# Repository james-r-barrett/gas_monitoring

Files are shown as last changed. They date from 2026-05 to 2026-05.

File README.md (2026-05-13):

# Canary Gas Monitoring

An open-source, networked gas monitoring system for laboratory growth chambers, built around the ESP32-S3 microcontroller. Measures CO₂ (and optionally O₂) continuously, logs data to an onboard SD card, and pushes readings to a central Grafana dashboard via a Raspberry Pi hub.

---

## Features

- **Two sensor variants** — CO₂-only and combined CO₂/O₂
- **Local web interface** — connect directly to each sensor's WiFi hotspot to view live readings, graphs, calibration logs, and download CSV data
- **Networked monitoring** — sensors push to a Raspberry Pi hub, which forwards to Grafana Cloud for remote access
- **Offline capable** — all data logged to SD card indefinitely; Pi connection is optional
- **Automatic time sync** — from Raspberry Pi on connection, or from any browser as fallback
- **Configurable** — read interval, graph window, device name, location, WiFi credentials all adjustable from the web interface without reflashing
- **Calibration** — K30 CO₂ sensor calibration (0 ppm and 400 ppm) via web interface and touchscreen; O₂ sensor via hardware button
- **Optional solenoid control** — for automated CO₂ dosing (hardware provision included)

---

## Repository Structure

```
gas-monitor/
├── hardware/
│   ├── bom/                    # Bills of materials (CSV)
│   └── schematics/             # Wiring schematics (SVG/PDF)
├── firmware/
│   ├── co2_monitor/            # CO₂-only firmware (Arduino sketch)
│   └── co2_o2_monitor/         # CO₂ + O₂ firmware (Arduino sketch)
├── server/                     # Raspberry Pi server (Python/Flask)
├── laptop-bridge/              # USB sensor bridge scripts (Windows/Linux)
└── docs/
    └── assembly/               # Step-by-step build guide with images
```

---

## Sensor Variants

| Feature | CO₂ only | CO₂ + O₂ |
|---|---|---|
| CO₂ measurement | ✓ K30 NDIR (0–10,000 ppm) | ✓ K30 NDIR (0–10,000 ppm) |
| O₂ measurement | — | ✓ SEN0322 (0–25%) |
| Display | ✓ 1.47" touchscreen | ✓ 1.47" touchscreen |
| SD logging | ✓ | ✓ |
| Local web UI | ✓ | ✓ |
| Pi push | ✓ | ✓ |
| O₂ sensor lifetime | — | ~2 years (replaceable) |

---

## Quick Start

1. See [`hardware/bom/`](hardware/bom/) for the parts list
2. See [`docs/assembly/`](docs/assembly/) for the build guide
3. See [`firmware/`](firmware/) for Arduino IDE setup and flashing instructions
4. See [`server/`](server/) for Raspberry Pi setup
5. See [`laptop-bridge/`](laptop-bridge/) for the USB analyser bridge (optional)

---

## System Overview

```
┌─────────────────────┐     WiFi (GasMonitor AP)    ┌──────────────────────┐
│  ESP32 sensor unit  │ ──────────────────────────► │   Raspberry Pi hub   │
│  (one per chamber)  │                             │                      │
└─────────────────────┘                             │  InfluxDB  (local)   │
                                                    │  Flask receiver      │
┌─────────────────────┐     USB serial + WiFi       │  → Grafana Cloud     │
│  Windows/Linux      │ ──────────────────────────► │                      │
│  laptop (optional)  │                             └──────────────────────┘
│  Minir-5 + K30 1%   │
└─────────────────────┘
```

---

## Licence

see [LICENSE](LICENSE)

## Citation

If you use this system in published research, please cite this repository:

> Barrett, J.R. (2026). Lab Gas Monitor. GitHub. https://github.com/james-r-barrett/gas-monitor

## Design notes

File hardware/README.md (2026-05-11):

# Hardware

This folder contains all hardware documentation for the gas monitor sensor units.

```
hardware/
├── bom/            # Bills of materials (CSV) — one per sensor variant
├── schematics/     # Wiring schematics
└── 3d-print/       # 3D print files and print settings
```

## Sensor Variants

There are two hardware variants. They share the same ESP32-S3 base platform and differ only in the addition of the O₂ sensor and a modified enclosure lid.

### CO₂-only

The standard variant. Measures CO₂ concentration using the SenseAir K30 NDIR sensor. Suitable for the majority of growth chamber applications.

### CO₂ + O₂

Adds a DFRobot SEN0322 electrochemical oxygen sensor to the I²C bus. The O₂ sensor shares the same I²C bus as the touchscreen controller (both run at 3.3V logic but the SEN0322 requires a 5V VCC supply). The enclosure lid has an additional port for the O₂ sensor body.

## Key Design Decisions

**Level shifter for K30:** The SenseAir K30 operates at 5V UART logic. The ESP32-S3 GPIO is 3.3V. A Pololu 4-channel bidirectional level shifter is used between them. The LV reference must be connected to the ESP32's 3.3V rail and the HV reference to the USB 5V (VBUS) rail.

**O₂ sensor power:** The SEN0322 operates at 3.3-5.5V VCC with  3.3V-compatible I²C logic. It may be powered from VBUS (5V), or the 3.3V regulator. The I²C SDA/SCL lines connect directly to the ESP32 GPIO without a level shifter.

**SD card interface:** The ESP32-S3 uses 4-bit SDMMC mode for SD card access, which is significantly faster than SPI mode. The pin assignments are fixed by the SDMMC peripheral and cannot be remapped.

**Power budget:** At peak load the system draws approximately 500–600 mA:
- K30 CO₂ sensor: ~200 mA
- ESP32-S3 + display: ~300 mA  
- SEN0322 O₂ sensor: <10 mA
- Other: <20 mA

A quality USB-C supply rated at ≥2A is recommended. Cheap supplies cause intermittent brown-outs that can corrupt SD card writes.

## I²C Bus

The I²C bus (SDA GPIO42, SCL GPIO41) is shared between:

- AXS5106L touch controller (address 0x63)
- SEN0322 O₂ sensor (address 0x73, set by dial switch position 3) — CO₂+O₂ variant only

There are no address conflicts between these devices.

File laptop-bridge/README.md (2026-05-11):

# Laptop Bridge

Python scripts for reading USB-connected gas analysers on a Windows or Linux laptop and pushing their data to the Raspberry Pi hub. This is an optional component — only needed if you have analysers connected via USB rather than the ESP32-based sensor units.

In our lab the laptop monitors two mixing bottle supplies:

- **Minir-5** (orange bottle) — 1–5% CO₂ mix, COM3 / `/dev/ttyMINIR`
- **K30 1%** (clear bottle) — ambient/low CO₂ supply, COM4 / `/dev/ttyK30`

---

## Files

| File | Purpose |
|---|---|
| `minir_pusher.py` | Reads Minir-5 via ASCII protocol and pushes to Pi |
| `k30_pusher.py` | Reads K30 via Modbus binary protocol and pushes to Pi |
| `minir_calibration.py` | GUI calibration tool for the Minir-5 |
| `k30_calibration.py` | GUI calibration tool for the K30 |

---

## Requirements

```bash
pip install pyserial requests
```

On Linux, also add your user to the `dialout` group and log out/in:
```bash
sudo usermod -a -G dialout $USER
```

---

## Configuration

Edit the top of each pusher script to match your setup:

```python
# minir_pusher.py
SERIAL_PORT   = "COM3"          # Windows
# SERIAL_PORT = "/dev/ttyMINIR" # Linux (with udev rule)
PI_HOST       = "192.168.50.1"
PI_PORT       = 5000
SENSOR_ID     = "1-5% Mix"
LOCATION      = "Orange mixing bottle"

# k30_pusher.py
SERIAL_PORT   = "COM4"          # Windows
# SERIAL_PORT = "/dev/ttyK30"   # Linux (with udev rule)
PI_HOST       = "192.168.50.1"
PI_PORT       = 5000
SENSOR_ID     = "<400 ppm Mix"
LOCATION      = "Clear mixing bottle"
```

---

## Running

### Windows — run both scripts together

Create `start_sensors.bat`:
```batch
@echo off
cd /d C:\path\to\laptop-bridge
start "Minir5" python minir_pusher.py
start "K30"   python k30_pusher.py
```

Drop a shortcut to this file in `shell:startup` to run on login.

### Linux — run as systemd services

Create `/etc/systemd/system/minir-pusher.service`:
```ini
[Unit]
Description=Minir-5 Gas Sensor Pusher
After=network.target

[Service]
ExecStart=/usr/bin/python3 /home/user/laptop-bridge/minir_pusher.py
Restart=always
RestartSec=10
User=user

[Install]
WantedBy=multi-user.target
```

Repeat for `k30-pusher.service`. Then:
```bash
sudo systemctl enable --now minir-pusher k30-pusher
```

---

## Linux: Persistent Serial Port Names (recommended)

On Linux the USB serial ports can be assigned different device names (`/dev/ttyUSB0`, `/dev/ttyUSB1`) depending on plug order. Use udev rules to assign stable names.

Find the USB serial numbers:
```bash
udevadm info -a -n /dev/ttyUSB0 | grep -E "serial|idVendor|idProduct"
udevadm info -a -n /dev/ttyUSB1 | grep -E "serial|idVendor|idProduct"
```

Create `/etc/udev/rules.d/99-gas-sensors.rules`:
```
SUBSYSTEM=="tty", ATTRS{idVendor}=="XXXX", ATTRS{serial}=="MINIR_SERIAL_HERE", SYMLINK+="ttyMINIR"
SUBSYSTEM=="tty", ATTRS{idVendor}=="XXXX", ATTRS{serial}=="K30_SERIAL_HERE",   SYMLINK+="ttyK30"
```

Reload:
```bash
sudo udevadm control --reload-rules && sudo udevadm trigger
```

The devices will now always appear as `/dev/ttyMINIR` and `/dev/ttyK30`.

---

## Protocols

### Minir-5 (ASCII)

| Command | Sends | Response | Description |
|---|---|---|---|
| `Z\r\n` | — | `  Z XXXXX` | Read CO₂ — value × 10 = ppm |
| `U\r\n` | — | `  U XXXXX` | Unlock for calibration |
| `X NNNN\r\n` | — | `  X XXXXX` | Calibrate — NNNN = target_ppm / 10 |

Example: `Z 03050` → 30,500 ppm

### K30 (Modbus binary)

| Bytes | Description |
|---|---|
| `FE 44 00 08 02 9F 25` | Read CO₂ command (7 bytes) |
| `FE 44 02 HH LL XX XX` | Response — CO₂ = (HH × 256 + LL) ppm |

Example response `FE 44 02 00 61 79 0C` → bytes[3:5] = `0x00 0x61` = 97 ppm

---

## Calibration Tools

The calibration tools (`minir_calibration.py` and `k30_calibration.py`) are standalone GUI applications built with Python's tkinter — no additional packages required beyond pyserial.

**Important:** The pusher script and calibration tool cannot both have the serial port open simultaneously. Stop the relevant pusher before running the calibration tool, then restart it afterwards.

### K30 calibration tool

- Connects to K30 on the selected COM port
- Shows live CO₂ reading (updates every 5 seconds)
- Provides 0 ppm and 400 ppm calibration buttons with confirmation dialogs
- Calibration sequence: sends unlock command → calibration command → 8-second settle → reads back result
- Includes on-screen reminders about the departmental compressed air line limitation

### Minir-5 calibration tool

- Connects to Minir-5 on the selected COM port
- Shows live CO₂ reading (updates every 5 seconds)
- Accepts any target concentration (free entry + presets at 1k, 5k, 10k, 20k, 30k, 50k ppm)
- Calibration sequence: `U` unlock → `X NNNN` calibration command → settle → verify confirmed value
- Warns if the sensor's confirmed calibration point differs from the target by more than 100 ppm

---

## Troubleshooting

| Problem | Action |
|---|---|
| `Cannot open COM3/COM4` | Check Device Manager — port may have changed number. Update `SERIAL_PORT` in script. |
| No data in Grafana | Confirm laptop is connected to `GasMonitor` WiFi. Check script log output for POST errors. |
| Readings are ×10 wrong | Verify Minir-5 multiplier — raw value × 10 = ppm for the Minir protocol. |
| K30 returns -1 or no response | Check USB cable and level shifter wiring. Try power-cycling the K30. |
| Calibration tool won't connect | Stop the pusher script first — both tools cannot share the serial port. |

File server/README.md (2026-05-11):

# Raspberry Pi Server

The Raspberry Pi acts as the central hub for the sensor network. It:

1. Broadcasts a WiFi access point (`GasMonitor`) that the sensors connect to
2. Provides time synchronisation to sensors on connection
3. Receives sensor readings via HTTP POST
4. Stores readings in a local InfluxDB instance
5. Forwards readings to Grafana Cloud

---

## Hardware

- Raspberry Pi 5 (2GB RAM tested; 4GB recommended for comfort)
- microSD card for Pi OS (16GB minimum)
- Ethernet cable (for network connection)
- Power supply (official Pi 5 USB-C 27W recommended)

---

## OS Setup

Flash **Raspberry Pi OS Lite (64-bit)** using [Raspberry Pi Imager](https://www.raspberrypi.com/software/).

In the Imager settings before flashing:

- Hostname: `gasmonitor.local`
- Enable SSH
- Set username and password

Boot the Pi and SSH in:
```bash
ssh pi@gasmonitor.local
```

Update:
```bash
sudo apt update && sudo apt upgrade -y
```

---

## WiFi Access Point Setup

The Pi broadcasts `GasMonitor` on its wireless interface while using ethernet for university network connectivity.

> ⚠️ **For most university networks it is not permitted to operate the Pi as an access point to the university. IPv4 forwarding must be disabled.**

### Disable IPv4 forwarding
Disable immediately:
```bash
sudo sysctl -w net.ipv4.ip_forward=0
```
Make persistent:
```bash
sudo nano /etc/sysctl.conf
```
Add:
```
net.ipv4.ip_forward=0
```
Apply:
```
sudo sysctl -p
```

### Install packages
```bash
sudo apt install -y hostapd dnsmasq
sudo systemctl stop hostapd dnsmasq
```

### Static IP for wlan0
```bash
sudo nano /etc/dhcpcd.conf
```
Add at the bottom:
```
interface wlan0
    static ip_address=192.168.50.1/24
    nohook wpa_supplicant
```

### DHCP server (dnsmasq)
```bash
sudo mv /etc/dnsmasq.conf /etc/dnsmasq.conf.orig
sudo nano /etc/dnsmasq.conf
```
```
interface=wlan0
dhcp-range=192.168.50.10,192.168.50.50,255.255.255.0,24h
domain=local
address=/gasmonitor.local/192.168.50.1
```

### Access point (hostapd)
```bash
sudo nano /etc/hostapd/hostapd.conf
```
```
interface=wlan0
driver=nl80211
ssid=GasMonitor
hw_mode=g
channel=7
wpa=2
wpa_passphrase=your set password here
wpa_key_mgmt=WPA-PSK
rsn_pairwise=CCMP
```

```bash
sudo nano /etc/default/hostapd
# Change: DAEMON_CONF="" → DAEMON_CONF="/etc/hostapd/hostapd.conf"
```

### Enable and reboot
```bash
sudo systemctl unmask hostapd
sudo systemctl enable hostapd dnsmasq
sudo reboot
```

After reboot, `GasMonitor` WiFi should be visible. Connect your laptop to it and verify SSH still works at `192.168.50.1`.

---

## InfluxDB

```bash
wget -q https://repos.influxdata.com/influxdata-archive_compat.key
echo '393e8779c89ac8d958f81f942f9ad7fb82a25e133faddaf92e15b16e6ac9ce4c influxdata-archive_compat.key' | sha256sum -c
cat influxdata-archive_compat.key | gpg --dearmor | sudo tee /etc/apt/trusted.gpg.d/influxdata-archive_compat.gpg > /dev/null
echo 'deb [signed-by=/etc/apt/trusted.gpg.d/influxdata-archive_compat.gpg] https://repos.influxdata.com/debian stable main' | sudo tee /etc/apt/sources.list.d/influxdata.list
sudo apt update && sudo apt install -y influxdb2
sudo systemctl enable --now influxdb
```

Open `http://192.168.50.1:8086` in a browser connected to `GasMonitor` WiFi and complete the setup wizard:

- Organisation: `lab`
- Bucket: `sensors`
- Generate an **All Access API token** and save it — you'll need it below

---

## Flask Receiver

### Install dependencies
```bash
sudo apt install -y python3-flask
pip3 install influxdb-client requests --break-system-packages
```

### Install server script
```bash
mkdir ~/gas_project
cp server.py ~/gas_project/
nano ~/gas_project/server.py
# Edit: paste your InfluxDB token into LOCAL_TOKEN
# Edit: paste your Grafana Cloud credentials into CLOUD_USER and CLOUD_TOKEN
```

### Test
```bash
python3 ~/gas_project/server.py
```

From another terminal or device on the `GasMonitor` network:
```bash
curl -X POST http://192.168.50.1:5000/sensor-data \
  -H "Content-Type: application/json" \
  -d '{"sensor_id":"test","location":"test","co2":500}'
```

You should see `{"status":"success"}`.

### Run as a system service
```bash
sudo nano /etc/systemd/system/gasreceiver.service
```
```ini
[Unit]
Description=Gas Sensor Data Receiver
After=network.target influxdb.service
Requires=influxdb.service

[Service]
ExecStart=/usr/bin/python3 /home/pi/gas_project/server.py
WorkingDirectory=/home/pi/gas_project
Restart=always
RestartSec=5
User=pi

[Install]
WantedBy=multi-user.target
```
```bash
sudo systemctl enable --now gasreceiver
sudo journalctl -u gasreceiver -f   # watch logs
```

---

## Grafana

```bash
sudo mkdir -p /etc/apt/keyrings/
wget -q -O - https://apt.grafana.com/gpg.key | gpg --dearmor | sudo tee /etc/apt/keyrings/grafana.gpg > /dev/null
echo "deb [signed-by=/etc/apt/keyrings/grafana.gpg] https://apt.grafana.com stable main" | sudo tee /etc/apt/sources.list.d/grafana.list
sudo apt update && sudo apt install -y grafana
sudo systemctl enable --now grafana-server
```

Access local Grafana at `http://192.168.50.1:3000` (default login: `admin` / `admin`).

Add InfluxDB as a data source:

- Type: **InfluxDB**
- Query language: **Flux**
- URL: `http://localhost:8086`
- Organisation: `lab`
- Token: paste your InfluxDB token
- Default bucket: `sensors`

---

## Grafana Cloud (optional)

For remote access without a VPN, the server script forwards readings to Grafana Cloud using the InfluxDB line protocol over HTTPS. Configure `CLOUD_URL`, `CLOUD_USER`, and `CLOUD_TOKEN` in `server.py` with credentials from your Grafana Cloud stack.

---

## API Endpoints

The receiver exposes the following HTTP endpoints:

| Endpoint | Method | Description |
|---|---|---|
| `/sensor-data` | POST | Receive a reading from a sensor |
| `/time` | GET | Return current Unix timestamp (used by sensors for time sync) |
| `/health` | GET | Health check |
| `/sensors` | GET | List last reading from each sensor |

### POST /sensor-data payload

```json
{
  "sensor_id": "chamber1",
  "location": "Growth Room A",
  "co2": 850,
  "o2": 20.91,
  "uptime": 3600,
  "timestamp": 1746540130
}
```

Fields `o2`, `uptime`, and `timestamp` are optional. If `timestamp` is provided and valid (>1700000000), it is used as the InfluxDB write time; otherwise the Pi's system time is used.

---

## Troubleshooting

| Problem | Action |
|---|---|
| `GasMonitor` WiFi not appearing | `sudo systemctl status hostapd` — check for errors |
| Sensors not connecting to Pi | Verify sensor WiFi credentials match `GasMonitor` / `your set password` |
| No data in InfluxDB | Check `sudo journalctl -u gasreceiver -f` for POST errors |
| Timestamps wrong in Grafana | Run `timedatectl` on Pi — NTP must be active and synced |
| Pi can't reach Grafana Cloud | Check ethernet connection: `curl https://grafana.net` |

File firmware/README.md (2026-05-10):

# Firmware

Two Arduino sketches are provided. Choose the one matching your hardware variant.

| Folder | Variant | Sketch file |
|---|---|---|
| `co2_monitor/` | CO₂ only | `co2_monitor.ino` |
| `co2_o2_monitor/` | CO₂ + O₂ | `co2_o2_monitor.ino` |

---

## Prerequisites

### Arduino IDE

Download and install [Arduino IDE 2.x](https://www.arduino.cc/en/software) (2.0 or later recommended).

### ESP32 Board Package

1. Open Arduino IDE → **File → Preferences**
2. In *Additional boards manager URLs*, add:
   ```
   https://raw.githubusercontent.com/espressif/arduino-esp32/gh-pages/package_esp32_index.json
   ```
3. Open **Tools → Board → Boards Manager**
4. Search for `esp32` and install **esp32 by Espressif Systems** (version 3.x recommended)

### Board Selection

- Board: **ESP32S3 Dev Module**
- PSRAM: **OPI PSRAM** (required — the firmware allocates history buffers in PSRAM)
- Flash size: **16MB**
- Partition scheme: **Default 4MB with spiffs** (or any scheme with ≥1.5MB app)
- Upload speed: **921600**

> **Important:** PSRAM must be enabled. Without it the large history buffers (up to 345,600 readings) will exhaust internal SRAM immediately.

---

## Required Libraries

Install all of the following via **Tools → Manage Libraries** in Arduino IDE:

| Library | Author | Install name |
|---|---|---|
| Arduino_GFX_Library | moononournation | `Arduino_GFX_Library` |
| esp_lcd_touch_axs5106l | — | Search `axs5106l` |
| DFRobot_OxygenSensor | DFRobot | `DFRobot_OxygenSensor` (CO₂+O₂ variant only) |

The following libraries are included with the ESP32 Arduino core and do not need separate installation:

- `WiFi`
- `WebServer`
- `Wire`
- `SD_MMC`
- `HTTPClient`

---

## Configuration

Before flashing, review the top of the sketch and adjust as needed:

```cpp
// WiFi access point credentials for this sensor's own hotspot
char apSSID[32] = "CO2Monitor";
char apPass[32] = "co2monitor123";

// Raspberry Pi network credentials (if using Pi hub)
const char* PI_SSID = "GasMonitor";
const char* PI_PASS = "*set your own*";
const char* PI_HOST = "192.168.50.1";
const int   PI_PORT = 5000;

// Sensor identity (also configurable via web UI without reflashing)
char deviceName[32] = "CO2 Monitor";
char sensorID[32]   = "sensor1";
char location[32]   = "chamber1";
```

All of these values can also be changed at runtime via the sensor's web interface at `192.168.4.1` — you do not need to reflash to rename a sensor or change WiFi credentials.

---

## Flashing

1. Connect the ESP32-S3 dev kit to your computer via USB-C
2. Open the sketch folder in Arduino IDE (`co2_monitor/co2_monitor.ino` or `co2_o2_monitor/co2_o2_monitor.ino`)
3. Select the correct port under **Tools → Port**
4. Click **Upload** (→)

If the board is not detected, hold the **BOOT** button on the ESP32 while pressing **Reset**, then release both and retry upload.

### First boot

On first boot with a blank SD card:
- The device will create `settings.json` on the SD card with default values
- Time sync will show a splash screen — connect to the sensor's WiFi hotspot and open `192.168.4.1` to sync time from your browser, or connect to the Raspberry Pi network to sync automatically

---

## SD Card Setup

Format the SD card as **FAT32** before first use. The firmware creates all required files automatically on first boot:

| File | Contents |
|---|---|
| `YYYY-MM.csv` | Monthly CO₂ (and O₂) log |
| `fallback.csv` | Readings taken before time sync (backdated on sync) |
| `settings.json` | Device configuration |
| `lasttime.txt` | Saved timestamp for reboot persistence |
| `lastcal.txt` | Most recent calibration record |
| `cal_log.csv` | Full calibration history |

---

## Operational Modes

The firmware operates in two modes automatically — no configuration required:

### Mode 1: Pi-connected (normal operation)
- Sensor connects to `GasMonitor` WiFi at boot
- Time is synced automatically from the Pi
- Readings are pushed to the Pi/Grafana every read cycle
- Green dot indicator shown on device display

### Mode 2: Standalone (Pi unavailable)
- Sensor shows a splash screen prompting time sync via browser
- Connect any device to the sensor's own WiFi hotspot
- Navigate to `192.168.4.1` — time syncs automatically from your browser
- Full local functionality continues (logging, web UI, graphs)
- Data recorded to `fallback.csv` until time sync; backdated automatically on sync

---

## Pin Reference

### Common to both variants

| Function | GPIO |
|---|---|
| Display SPI MOSI | 39 |
| Display SPI SCLK | 38 |
| Display CS | 21 |
| Display DC | 45 |
| Display RST | 40 |
| Display backlight | 46 |
| Touch SDA | 42 |
| Touch SCL | 41 |
| Touch RST | 47 |
| Touch INT | 48 |
| K30 TX (to sensor) | 43 |
| K30 RX (from sensor) | 44 |
| SD CLK | 16 |
| SD CMD | 15 |
| SD D0 | 17 |
| SD D1 | 18 |
| SD D2 | 13 |
| SD D3 | 14 |

### CO₂ + O₂ variant only

| Function | GPIO |
|---|---|
| O₂ sensor SDA | 42 (shared with touch) |
| O₂ sensor SCL | 41 (shared with touch) |
| O₂ sensor VCC | 3V3 |

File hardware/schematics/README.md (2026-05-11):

# Schematics

Wiring schematics for both sensor variants.

| File | Variant |
|---|---|
| `co2_schematic.png` | CO₂-only sensor |
| `co2_o2_schematic.png` | CO₂ + O₂ sensor |

---

## CO₂-only — Full Connection Reference

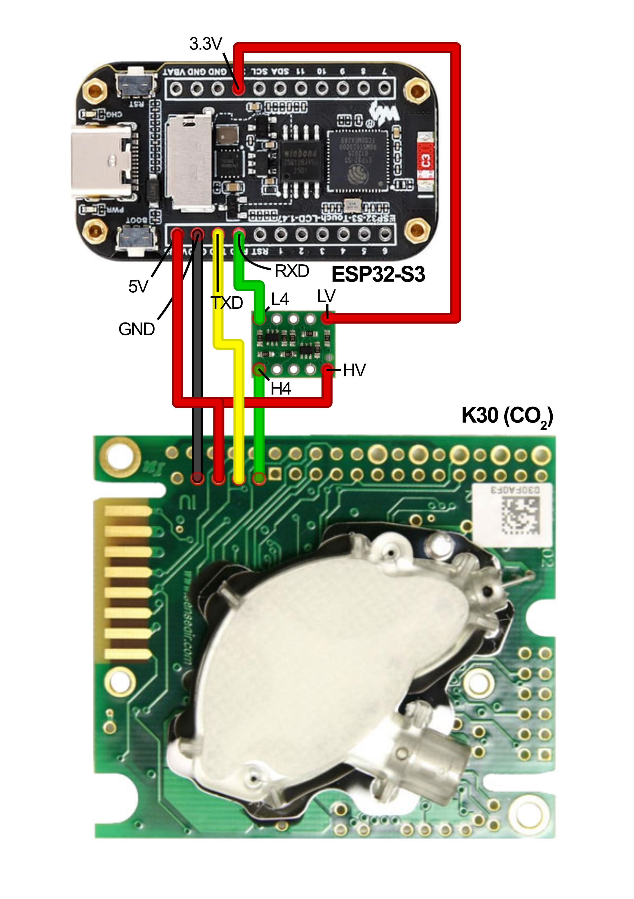
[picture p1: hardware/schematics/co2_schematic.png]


### Power

| From | To | Notes |
|---|---|---|
| USB-C 5V (VBUS) | ESP32 5V pin | Main supply |
| USB-C GND | ESP32 GND | Common ground |
| USB-C VBUS | Level shifter HV | 5V reference for K30 side |
| ESP32 3.3V | Level shifter LV | 3.3V reference for ESP32 side |

### Display (SPI — built into Waveshare dev kit)

| ESP32 GPIO | Function |
|---|---|
| 39 | SPI MOSI |
| 38 | SPI SCLK |
| 21 | Display CS |
| 45 | Display DC |
| 40 | Display RST |
| 46 | Backlight (PWM) |

> These connections are internal to the Waveshare board and require no external wiring.

### Touchscreen (I²C — built into Waveshare dev kit)

| ESP32 GPIO | AXS5106L pin | Notes |
|---|---|---|
| 42 | SDA | Internal to board |
| 41 | SCL | Internal to board |
| 47 | RST | Internal to board |
| 48 | INT | Internal to board |

> These connections are internal to the Waveshare board and require no external wiring.

### SD Card (SDMMC 4-bit — built into Waveshare dev kit)

| ESP32 GPIO | SD pin |
|---|---|
| 16 | CLK |
| 15 | CMD |
| 17 | D0 |
| 18 | D1 |
| 13 | D2 |
| 14 | D3 |

> These connections are internal to the Waveshare board and require no external wiring.

### K30 CO₂ Sensor (UART via level shifter)

| ESP32 GPIO | Level shifter | K30 pin | Notes |
|---|---|---|---|
| 43 (TX) | — | RXD | ESP32 TX → K30 RX |
| 44 (RX) | HV3 → LV3 | TXD | K30 TX → ESP32 RX |
| 3.3V | LV ref | — | Level shifter reference |
| VBUS (5V) | HV ref | — | Level shifter reference |
| GND | — | GND | Common ground |
| VBUS (5V) | — | G+ (VCC) | K30 power — must be 5V |

> **Note:** Do not use the K30's RST pin as the HV reference for the level shifter. Connect HV directly to the VBUS rail.

## CO₂ + O₂ — Additional Connections



All connections above apply, plus:

### SEN0322 O₂ Sensor (I²C, shared bus)

| SEN0322 pin | Connection | Notes |
|---|---|---|
| VCC | 3V3 (3.3V) | **3.3V not 5V** |
| GND | GND | Common ground |
| SDA | ESP32 GPIO42 | Shared with touch controller |
| SCL | ESP32 GPIO41 | Shared with touch controller |
| Dial switch | Position 3 | Sets I²C address to 0x73 |

---

## Schematic Notes

- All GND connections share a common ground rail.
- The Waveshare ESP32-S3 dev kit has an onboard 3.3V regulator. Do not exceed 600 mA total from VBUS.
- The level shifter RST pin (if present on your variant) is not used — leave it unconnected or tie to LV.
- GPIO pins 1–10 are all available for the solenoid or future expansion. GPIO1 is used in the firmware by default but any free GPIO can be substituted with a one-line firmware change.

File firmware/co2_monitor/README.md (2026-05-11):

# CO₂ Monitor Firmware

Arduino sketch for the **CO₂-only** sensor variant. For the combined CO₂ + O₂ variant see `../co2_o2_monitor/`.

## File

`co2_monitor.ino`

---

## What this firmware does

- Reads CO₂ concentration from a SenseAir K30 sensor over UART every 1–60 seconds (configurable)
- Displays live readings, trend indicator, and sparkline on the 1.47" touchscreen
- Logs all readings to a monthly CSV file on the SD card
- Hosts a local web interface at `192.168.4.1` (accessible from the sensor's own WiFi hotspot)
- Connects to the Raspberry Pi hub (`GasMonitor` WiFi) and pushes readings via HTTP POST
- Syncs time from the Pi on connection, or from a browser as fallback
- Stores min/max statistics over a rolling 12-hour window
- Supports K30 calibration (0 ppm and 400 ppm) from the web interface

---

## Setup

See the [firmware README](../README.md) for:
- Arduino IDE and board package installation
- Required libraries
- Board settings (PSRAM must be enabled)
- Flashing instructions

---

## Sensor-specific notes

### K30 UART wiring
The K30 runs at 5V UART logic and must be connected via a level shifter. See `hardware/schematics/` for the full wiring diagram.

### ABC (Automatic Baseline Correction)
The firmware disables ABC on every boot by sending the ABC-off command to the K30. This is essential for growth chamber use where the sensor is never exposed to outdoor air concentrations for the sustained periods ABC requires. Do not re-enable ABC.

### Calibration
Two calibration points are supported:
- **0 ppm** — using pure N₂ or a certified 0 ppm CO₂ / 21% O₂ / 79% N₂ mix
- **400 ppm** — using outdoor ambient air (preferred) or a certified reference gas

See the [calibration documentation](/docs/user-guide.md) for full procedure including the warning about using the departmental compressed air line.

---

## Display pages

Tap the main reading area to cycle through pages:

| Page | Content |
|---|---|
| Reading view | Live CO₂ value, trend arrow, 12h min/max, uptime/clock, sparkline |
| CO₂ graph | Full-resolution graph for the configured window (up to 96h) |

---

## Settings (configurable at runtime via web UI)

| Setting | Default | Description |
|---|---|---|
| Read interval | 5s | How often to poll the K30 |
| Graph window | 30 min | Time window for device display and web graph |
| Device name | CO2 Monitor | Shown on screen and used as Grafana sensor ID |
| Location | chamber1 | Location tag in Grafana |
| WiFi SSID | CO2Monitor | Sensor's own hotspot SSID |
| WiFi password | co2monitor123 | Sensor's own hotspot password |

All settings are saved to `settings.json` on the SD card and persist across reboots. WiFi changes require a reboot to take effect.

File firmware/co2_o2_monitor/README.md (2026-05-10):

# CO₂ + O₂ Monitor Firmware

Arduino sketch for the **combined CO₂ and O₂** sensor variant. For the CO₂-only variant see `../co2_monitor/`.

## File

`co2_o2_monitor.ino`

---

## What this firmware does

Everything the CO₂-only firmware does, plus:

- Reads O₂ concentration from a DFRobot SEN0322 sensor over I²C every read cycle
- Displays O₂ alongside CO₂ on the reading view with independent trend indicator
- Logs O₂ to the monthly CSV alongside CO₂ (`o2_pct` column)
- Includes O₂ in data pushed to the Raspberry Pi and Grafana
- Adds an O₂ graph as a third display page (cycle: reading → CO₂ graph → O₂ graph)
- Handles O₂ sensor absence gracefully — shows `--` if sensor not detected at boot

---

## Setup

See the [firmware README](../README.md) for:
- Arduino IDE and board package installation
- Required libraries — **DFRobot_OxygenSensor is additionally required for this variant**
- Board settings (PSRAM must be enabled)
- Flashing instructions

---

## Additional library

Install via Arduino IDE Library Manager:

| Library | Author |
|---|---|
| `DFRobot_OxygenSensor` | DFRobot |

---

## Sensor-specific notes

### SEN0322 I²C address
The O₂ sensor address is set by a dial switch on the board. **Set the dial to position 3** (I²C address `0x73`). This avoids conflict with the AXS5106L touch controller at `0x63`.

### SEN0322 power supply
The SEN0322 **must be powered from 5V (VBUS)**. Connecting VCC to the 3.3V rail will cause the electrochemical cell to give incorrect readings or fail to respond. The I²C SDA/SCL lines are 3.3V compatible and connect directly to the ESP32 GPIO.

### O₂ sensor initialisation
The firmware attempts to initialise the O₂ sensor with up to 5 retries at 500ms intervals during boot. If the sensor is not detected after all retries, the firmware continues without O₂ — all CO₂ functionality is unaffected. A retry loop is necessary because the SEN0322 requires ~2 seconds to stabilise after power-on.

### O₂ sensor lifetime
The electrochemical cell has a lifetime of approximately **2 years** from first use. Monitor for readings that drift consistently low or become unstable — this indicates the cell is near end of life. Replacement sensors are available from DFRobot.

### O₂ calibration
O₂ sensor calibration is performed by holding the **physical button on the back of the SEN0322 board** while the sensor is exposed to clean outdoor air (20.9% O₂). This is a hardware calibration and is not performed via the web interface. Under normal operating conditions recalibration should rarely be needed.

---

## Display pages

Tap the main reading area to cycle through three pages:

| Page | Content |
|---|---|
| Reading view | Live CO₂ and O₂ values, trend arrows, sparklines for both |
| CO₂ graph | Full-resolution CO₂ graph for the configured window |
| O₂ graph | Full-resolution O₂ graph for the configured window (auto-scaled) |

If the Pi is not connected and time has not been synced, tapping to the graph pages is blocked until time sync is complete.

---

## CSV log format

Monthly log files contain the following columns:

```
datetime,uptime_s,co2_ppm,o2_pct
2026-05-10 14:23:01,3601,842,20.91
```

---

## Settings (configurable at runtime via web UI)

| Setting | Default | Description |
|---|---|---|
| Read interval | 5s | How often to poll both sensors |
| Graph window | 30 min | Time window for device display and web graph |
| Device name | CO2 Monitor | Shown on screen and used as Grafana sensor ID |
| Location | chamber1 | Location tag in Grafana |
| WiFi SSID | CO2Monitor | Sensor's own hotspot SSID |
| WiFi password | co2monitor123 | Sensor's own hotspot password |

All settings are saved to `settings.json` on the SD card and persist across reboots.

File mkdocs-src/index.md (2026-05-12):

---
hide:
  - navigation
---

# Canary Gas Monitoring

<div class="hero-image">
  Assembled Lab Gas Monitor
</div>

<div class="hero-content">

An open-source, networked gas monitoring system for laboratory growth chambers, built around the ESP32-S3 microcontroller.

Continuously measures CO₂ (and optionally O₂), logs data locally to SD storage, and streams live telemetry to a central Grafana dashboard through a Raspberry Pi hub.

<div class="hero-tags">
  <span>ESP32-S3</span>
  <span>CO₂ Monitoring</span>
  <span>Grafana</span>
  <span>Open Source</span>
</div>

<div class="hero-buttons">
  <a href="https://github.com/james-r-barrett/gas_monitoring"
     target="_blank"
     class="hero-btn github-btn">

    <svg xmlns="http://www.w3.org/2000/svg"
         viewBox="0 0 496 512"
         width="16"
         height="16"
         fill="currentColor">

      <path d="M165.9 397.4c0 2-2.3 3.6-5.2 3.6-3.3.3-5.6-1.3-5.6-3.6 0-2 2.3-3.6 5.2-3.6 3-.3 5.6 1.3 5.6 3.6zM244.8 8C106.1 8 0 113.3 0 252c0 110.9 69.8 205.8 169.5 239.2 12.8 2.3 17.3-5.6 17.3-12.1 0-6.2-.3-40.4-.3-61.4 0 0-70 15-84.7-29.8 0 0-11.4-29.1-27.8-36.6 0 0-22.9-15.7 1.6-15.4 0 0 24.9 2 38.6 25.8 21.9 38.6 58.6 27.5 72.9 20.9 2.3-16 8.8-27.1 16-33.7-55.9-6.2-112.3-14.3-112.3-110.5 0-27.5 7.6-41.3 23.6-58.9-2.6-6.5-11.1-33.3 2.6-67.9 20.9-6.5 69 27 69 27 20-5.6 41.5-8.5 62.8-8.5s42.8 2.9 62.8 8.5c0 0 48.1-33.6 69-27 13.7 34.7 5.2 61.4 2.6 67.9 16 17.7 25.8 31.5 25.8 58.9 0 96.5-58.9 104.2-114.8 110.5 9.2 7.9 17 22.9 17 46.4 0 33.7-.3 75.4-.3 83.6 0 6.5 4.6 14.4 17.3 12.1C428.2 457.8 496 362.9 496 252 496 113.3 389.9 8 244.8 8z"/>
    </svg>

    View on GitHub
  </a>

  <a href="https://jamesrbarrett.grafana.net/public-dashboards/2842727a8849425480e023f71c46eba7"
     target="_blank"
     rel="noopener noreferrer"
     class="hero-btn grafana-btn">

    Open Mackinder Dashboard ↗
  </a>
</div>

</div>

<style>
.hero-image {
  margin: 1.5rem 0;
}

.hero-image img {
  width: 100%;
  border-radius: 18px;
  box-shadow: var(--md-shadow-z2);
  border: 1px solid var(--md-default-fg-color--lightest);
  display: block;
}

.hero-content {
  max-width: 900px;
  margin: 0 auto;
  font-size: 1.05rem;
  line-height: 1.75;
}

.hero-tags {
  display: flex;
  flex-wrap: wrap;
  gap: 0.6rem;
  margin: 1.5rem 0;
}

.hero-tags span {
  background: var(--md-code-bg-color);
  border: 1px solid var(--md-default-fg-color--lightest);
  padding: 0.4rem 0.8rem;
  border-radius: 999px;
  font-size: 0.82rem;
  font-weight: 600;
}

.hero-buttons {
  display: flex;
  flex-wrap: wrap;
  gap: 1rem;
  margin-top: 2rem;
}

.hero-btn {
  display: inline-flex;
  align-items: center;
  gap: 0.6rem;
  padding: 0.9rem 1.3rem;
  border-radius: 12px;
  text-decoration: none !important;
  font-weight: 600;
  transition: all 0.2s ease;
}

.hero-btn:hover {
  transform: translateY(-2px);
}

.github-btn {
  background: #111217;
  color: white !important;
}

.grafana-btn {
  background: #FFEE1A;
  color: black !important;
}
</style>

---
## Overview

<!-- PLACEHOLDER: Hero image showing the assembled sensor unit on a growth chamber -->
<!-- Replace with: ![Assembled sensor unit](images/hero.jpg) -->

The system was developed in the [Mackinder Lab](https://mackinderlab.weebly.com/) at the [Centre for Novel Agricultural Products (CNAP)](https://www.york.ac.uk/biology/centre-for-novel-agricultural-products/), University of York, to provide continuous, networked gas monitoring across multiple algae growth chambers.

Key design goals:

- **No cloud dependency for core function** — all data logged locally to SD card; Pi and Grafana are optional additions
- **Easy to deploy** — web-configurable without reflashing; each sensor is a self-contained unit
- **Long-term logging** — FAT32 SD card with >20 years capacity at 5-second intervals
- **Lab-realistic calibration** — explicit guidance for CO₂ calibration in a real laboratory gas supply context

---

## Features

- **Two sensor variants** — CO₂-only and combined CO₂/O₂
- **Touchscreen display** — live readings, trend indicators, sparkline history, and graph pages
- **Local web interface** — live readings, full-resolution graphs, calibration, settings, and CSV download at `192.168.4.1`
- **Networked monitoring** — sensors push to a Raspberry Pi hub forwarding to Grafana Cloud
- **Automatic time sync** — from Raspberry Pi on connection, or from any browser as fallback
- **Fully configurable at runtime** — read interval, graph window, device name, location, WiFi credentials via web UI
- **K30 CO₂ calibration** — 0 ppm and 400 ppm via touchscreen and web interface
- **USB analyser bridge** — Minir-5 and K30 1% mixing bottle monitors via laptop Python scripts
- **Optional solenoid control** — hardware provision for automated CO₂ dosing

---

## Sensor Variants

| Feature | CO₂ only | CO₂ + O₂ |
|---|---|---|
| CO₂ measurement | ✓ K30 NDIR (0–10,000 ppm) | ✓ K30 NDIR (0–10,000 ppm) |
| O₂ measurement | — | ✓ SEN0322 (0–25%) |
| Touchscreen display | ✓ 1.47" | ✓ 1.47" |
| SD card logging | ✓ | ✓ |
| Local web interface | ✓ | ✓ |
| Raspberry Pi push | ✓ | ✓ |
| O₂ sensor lifetime | — | ~2 years (replaceable) |

---

## System Architecture

<div class="arch-grid">

<div class="arch-box">
  <h3>ESP32 Sensor Units</h3>
  <p>One per growth chamber</p>
</div>

<div class="arch-arrow">→ WiFi (GasMonitor) →</div>

<div class="arch-box">
  <h3>Raspberry Pi Hub</h3>
  <ul>
    <li>Flask receiver</li>
    <li>InfluxDB (local)</li>
    <li>Grafana Cloud sync</li>
  </ul>
</div>

</div>

<div class="arch-grid">

<div class="arch-box">
  <h3>Windows / Linux Laptop</h3>
  <p>Minir-5 + K30 1%</p>
</div>

<div class="arch-arrow">→ WiFi (GasMonitor) →</div>

<div class="arch-box">
  <h3>Same Pipeline</h3>
  <p>Sent to Raspberry Pi hub</p>
</div>

</div>

<style>
.arch-grid {
  display: grid;
  grid-template-columns: 1fr auto 1fr;
  gap: 1rem;
  align-items: center;
  margin: 1.5rem 0;
}

.arch-box {
  background: var(--md-default-bg-color);
  border: 1px solid var(--md-default-fg-color--lightest);
  border-radius: 14px;
  padding: 1rem 1.2rem;
  box-shadow: var(--md-shadow-z1);
}

.arch-box h3 {
  margin-top: 0;
}

.arch-arrow {
  font-weight: 700;
  text-align: center;
  opacity: 0.7;
  white-space: nowrap;
}

@media (max-width: 900px) {
  .arch-grid {
    grid-template-columns: 1fr;
    text-align: center;
  }

  .arch-arrow {
    transform: rotate(90deg);
    margin: 0.5rem 0;
  }
}
</style>

<style>
.gallery-grid {
  display: grid;
  grid-template-columns: repeat(auto-fit, minmax(320px, 1fr));
  gap: 1rem;
  margin-top: 1rem;
}

.gallery-card {
  border-radius: 12px;
  overflow: hidden;
  background: var(--md-default-bg-color);
  border: 1px solid var(--md-default-fg-color--lightest);
  box-shadow: var(--md-shadow-z1);
}

.gallery-card img {
  width: 100%;
  display: block;
  height: auto;
}

.gallery-caption {
  padding: 0.9rem 1rem;
  font-size: 0.95rem;
}

.gallery-caption h3 {
  margin: 0 0 0.3rem 0;
  font-size: 1rem;
}

.gallery-caption p {
  margin: 0;
  opacity: 0.8;
  font-size: 0.85rem;
}

details.gallery-dropdown {
  margin-bottom: 1rem;
  border-radius: 12px;
  overflow: hidden;
  border: 1px solid var(--md-default-fg-color--lightest);
}

details.gallery-dropdown summary {
  cursor: pointer;
  padding: 1rem;
  font-weight: 600;
  background: var(--md-code-bg-color);
}
</style>

## Gallery

<details class="gallery-dropdown" open>
<summary>Hardware & Displays</summary>

<div class="gallery-grid">

<div class="gallery-card">
  Assembled sensor
  <div class="gallery-caption">
    <h3>Assembled Sensor</h3>
    <p>Fully assembled devices.</p>
  </div>
</div>

<div class="gallery-card">
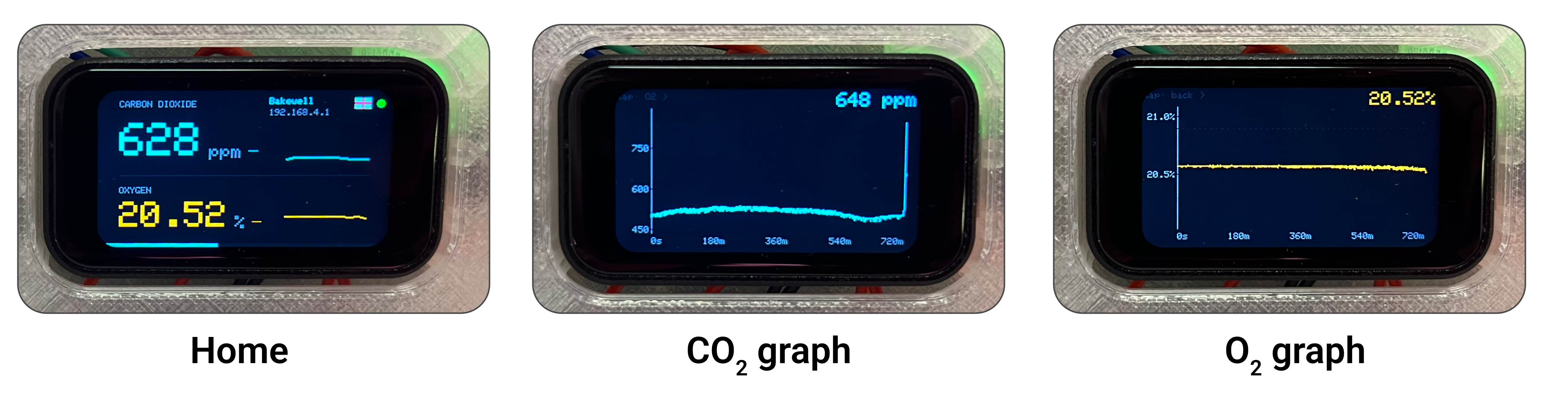
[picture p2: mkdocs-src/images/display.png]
Display screens
  
  <div class="gallery-caption">
    <h3>Display Screens</h3>
    <p>Snapshots of the screens shown on the combined device.</p>
  </div>
</div>

</div>
</details>

<details class="gallery-dropdown">
<summary>Web Interface</summary>

<div class="gallery-grid">

<div class="gallery-card">
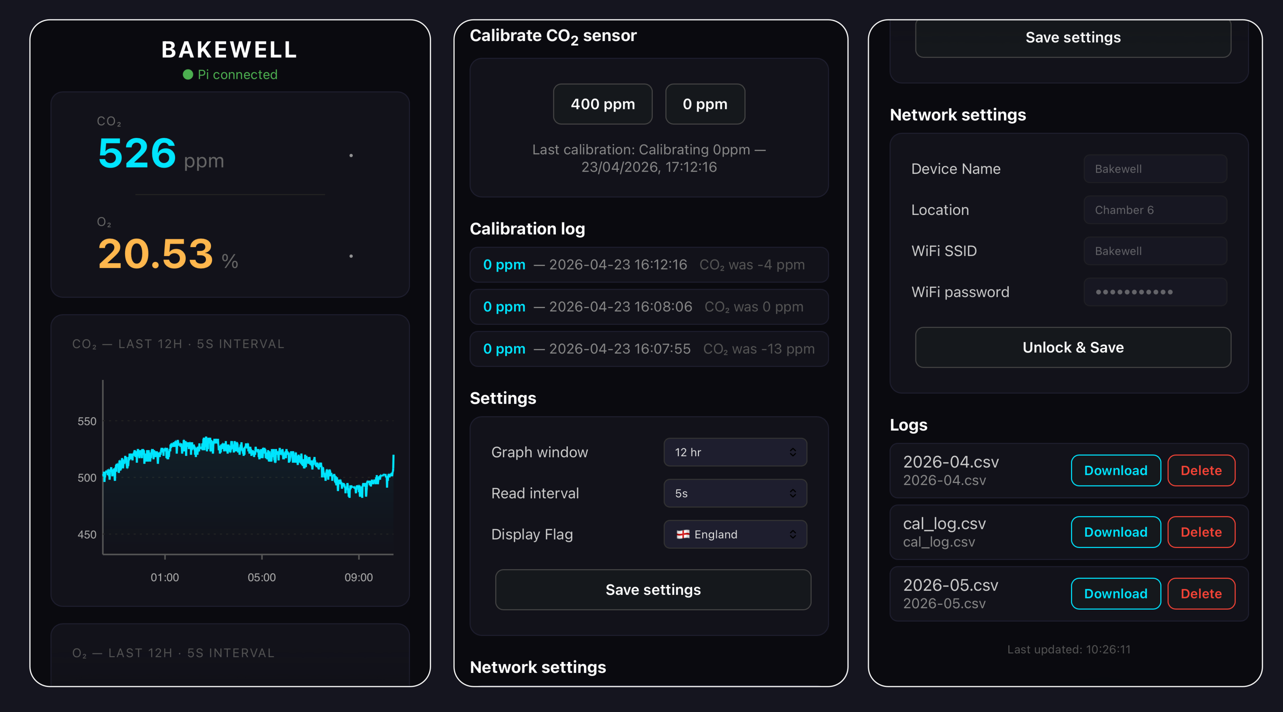
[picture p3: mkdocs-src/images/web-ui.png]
Web UI dashboard
  
  <div class="gallery-caption">
    <h3>Web UI</h3>
    <p>Browser-based monitoring interface.</p>
  </div>
</div>

<div class="gallery-card">
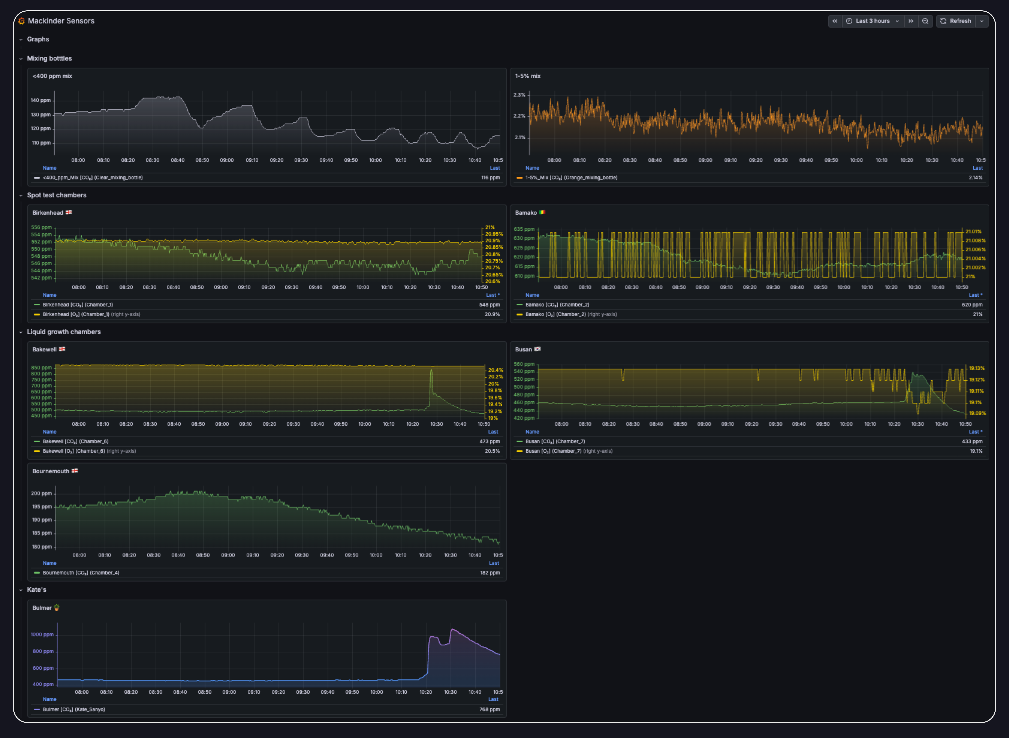
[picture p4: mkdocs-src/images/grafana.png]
Grafana dashboard
  
  <div class="gallery-caption">
    <h3>Grafana Dashboard</h3>
    <p>Live metrics and historical visualizations.</p>
  </div>
</div>

</div>
</details>
---

## Getting Started

<div style="display:grid; grid-template-columns:repeat(auto-fit, minmax(200px, 1fr)); gap:12px; margin:20px 0;">

  <a href="hardware/" style="text-decoration:none; background:#f8f9fa; border:1px solid #e0e0e0; border-radius:8px; padding:20px; display:block; color:inherit;">
    <div style="font-size:1.8em; margin-bottom:8px;">🔧</div>
    <div style="font-weight:bold; margin-bottom:4px;">Hardware</div>
    <div style="font-size:0.9em; color:#666;">Parts list, schematics, and 3D print files</div>
  </a>

  <a href="firmware/" style="text-decoration:none; background:#f8f9fa; border:1px solid #e0e0e0; border-radius:8px; padding:20px; display:block; color:inherit;">
    <div style="font-size:1.8em; margin-bottom:8px;">💾</div>
    <div style="font-weight:bold; margin-bottom:4px;">Firmware</div>
    <div style="font-size:0.9em; color:#666;">Arduino IDE setup, libraries, and flashing</div>
  </a>

  <a href="guides/assembly/" style="text-decoration:none; background:#f8f9fa; border:1px solid #e0e0e0; border-radius:8px; padding:20px; display:block; color:inherit;">
    <div style="font-size:1.8em; margin-bottom:8px;">📋</div>
    <div style="font-weight:bold; margin-bottom:4px;">Assembly</div>
    <div style="font-size:0.9em; color:#666;">Step-by-step build guide with photos</div>
  </a>

  <a href="server/" style="text-decoration:none; background:#f8f9fa; border:1px solid #e0e0e0; border-radius:8px; padding:20px; display:block; color:inherit;">
    <div style="font-size:1.8em; margin-bottom:8px;">🖥️</div>
    <div style="font-weight:bold; margin-bottom:4px;">Raspberry Pi</div>
    <div style="font-size:0.9em; color:#666;">Hub setup, InfluxDB, and Grafana</div>
  </a>

  <a href="guides/user-guide/" style="text-decoration:none; background:#f8f9fa; border:1px solid #e0e0e0; border-radius:8px; padding:20px; display:block; color:inherit;">
    <div style="font-size:1.8em; margin-bottom:8px;">📖</div>
    <div style="font-weight:bold; margin-bottom:4px;">User Guide</div>
    <div style="font-size:0.9em; color:#666;">Day-to-day operation and calibration</div>
  </a>

  <a href="laptop-bridge/" style="text-decoration:none; background:#f8f9fa; border:1px solid #e0e0e0; border-radius:8px; padding:20px; display:block; color:inherit;">
    <div style="font-size:1.8em; margin-bottom:8px;">🔌</div>
    <div style="font-weight:bold; margin-bottom:4px;">Laptop Bridge</div>
    <div style="font-size:0.9em; color:#666;">USB analyser scripts for Minir-5 and K30</div>
  </a>

</div>

---

## Built With

| Component | Role |
|---|---|
| [Waveshare ESP32-S3](https://www.waveshare.com) | Sensor microcontroller with touchscreen |
| [SenseAir K30](https://senseair.com) | NDIR CO₂ sensor |
| [DFRobot SEN0322](https://dfrobot.com) | Electrochemical O₂ sensor |
| [Raspberry Pi 5](https://www.raspberrypi.com) | Central hub and WiFi access point |
| [InfluxDB](https://influxdata.com) | Local time-series database |
| [Grafana](https://grafana.com) | Dashboard and remote monitoring |
| Arduino IDE | Firmware development |
| Autodesk Fusion | Enclosure 3D design |

---

## Acknowledgements

Developed at the [Centre for Novel Agricultural Products (CNAP)](https://www.york.ac.uk/cnap/), University of York.
Thanks to Mark Bentley [(Biology workshops)](https://www.york.ac.uk/biology/current-students-staff/mech-workshop/) for helping with the enclsoure design and print steps.

<!-- PLACEHOLDER: CNAP / University of York logo -->

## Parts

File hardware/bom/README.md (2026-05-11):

# Bills of Materials

Two BOMs are provided, one for each sensor variant.

| File | Variant |
|---|---|
| `bom_co2_only.csv` | CO₂-only sensor |
| `bom_co2_o2.csv` | Combined CO₂ + O₂ sensor |

## Notes

- Prices are approximate UK retail as of 2026 and will vary by supplier and region.
- The O₂ sensor (SEN0322) has a consumable electrochemical cell with a lifetime of approximately 2 years. Budget for periodic replacement.
- All other components (K30, ESP32, level shifter) have indefinite lifetimes under normal use.

## Suggested UK Suppliers

| Supplier | Good for |
|---|---|
| [The Pi Hut](https://thepihut.com/) | ESP32 boards, level shifters, general electronics |
| [RS Components](https://uk.rs-online.com) | MOSFETs, diodes, passive components |
| [Farnell](https://uk.farnell.com) | MOSFETs, diodes, passive components |
| [Mouser](https://mouser.com) | DFRobot SEN0322, sensor modules |
| [DigiKey](https://www.digikey.co.uk/) | SenseAir K30 |
| [Waveshare](https://waveshare.com) | ESP32-S3 dev kit |
| AliExpress | Budget duplicates of most components (longer lead times) |

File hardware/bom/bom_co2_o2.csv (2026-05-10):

Component | Part | Qty | Approx cost (GBP) | Part ID
Microcontroller | ESP32-S3 1.47" Touch Display Dev Board with SD Slot | 1 | 15.4 | WAV-31199
CO2 sensor | Senseair K30 FR | 1 | 44.9 | 030-8-0010
O2 sensor | Gravity: Electrochemical Oxygen / O2 Sensor (0-25%Vol, I2C) | 1 | 47.28 | SEN0322
Level shifter | Pololu Logic Level Shifter - 4-Channel, Bidirectional | 1 | 3.4 | POL-2595
SD card | microSD (any, FAT32 formatted) | 1 | 10 | e.g. SP016GBSTHBU1V10SP
Enclosure | 3D printed (PLA) | 1 | 3 | -
Fixings | M2 x 8 mm | 4 | 0.6 | -
Wiring | 24 AWG hook up wire (~50 cm) | 1 | 0.85 | e.g. RS: 207-5308
Power cable | Male USB Type A to Male, USB 2.0 USB Type C, Black, 2 m | 1 | 4.08 | e.g. RS: 895-0499
Power supply | Ansmann 12 W USB Adapter AC/DC Adapter UK 5V dc Output, 2.4 A | 1 | 7.5 | e.g. ANSMANN: 1001-0105-520
Total | - | - | 137.01 | -

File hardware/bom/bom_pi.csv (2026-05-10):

Component | Part | Qty | Approx cost (GBP) | Part ID
Pi 5 starer kit | Raspberry Pi 5 2GB Desktop Starter Kit, White | 1 | 84 | RPI5-HDMISK-WHT2GB

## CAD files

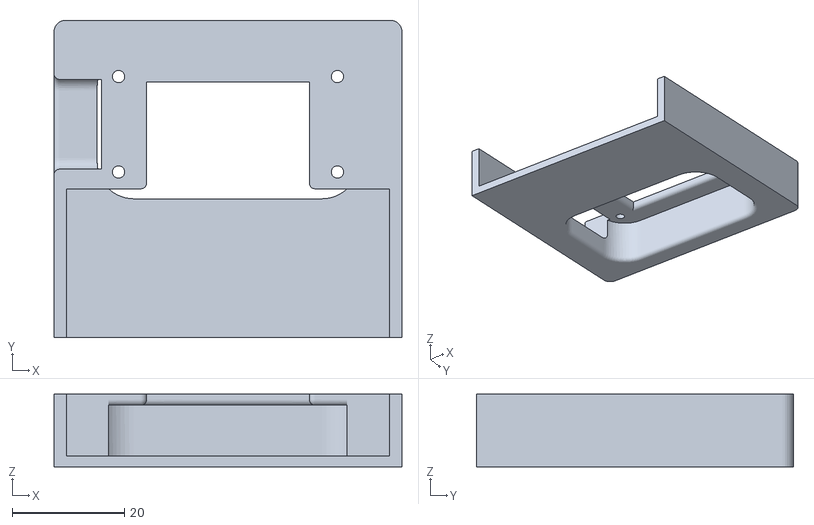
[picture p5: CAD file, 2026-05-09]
hardware/3d-print/stl/co2/co2_fascia.stl
62.0 x 56.5 x 13.0

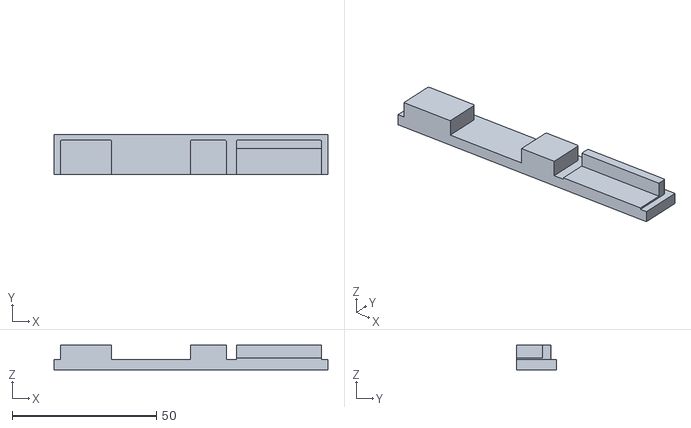
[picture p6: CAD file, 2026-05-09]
hardware/3d-print/stl/co2_o2/co2_o2_insert.stl
95.0 x 14.0 x 8.50

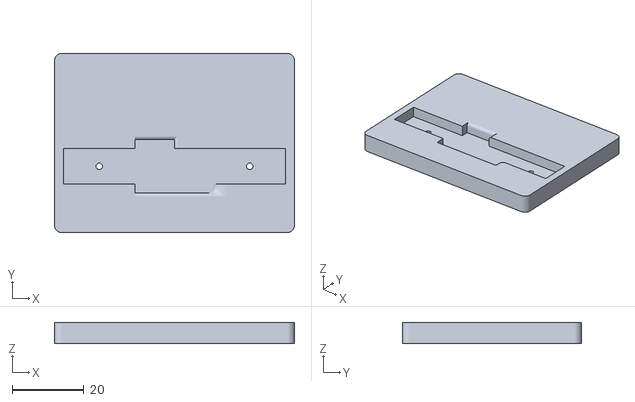
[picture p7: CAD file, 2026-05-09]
hardware/3d-print/stl/co2/co2_base.stl
67.0 x 50.0 x 6.00

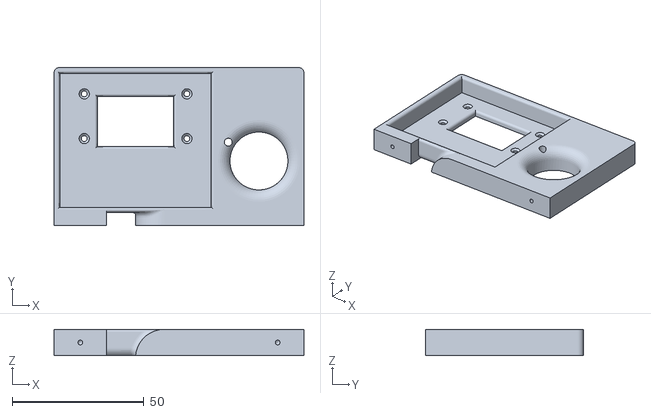
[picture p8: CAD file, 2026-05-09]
hardware/3d-print/stl/co2_o2/co2_o2_plate.stl
95.0 x 60.0 x 10.0

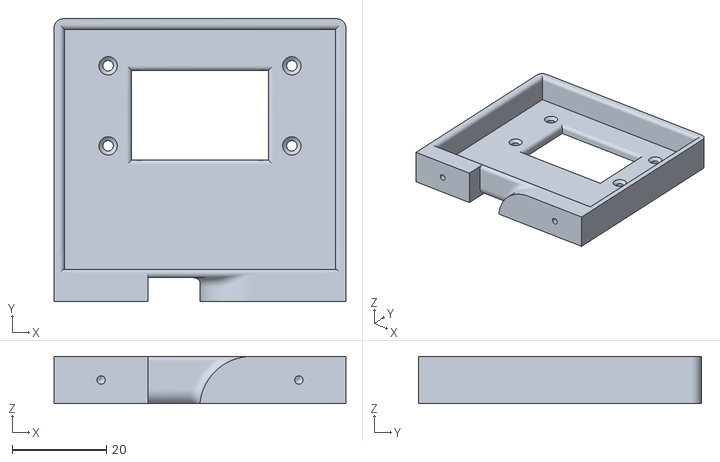
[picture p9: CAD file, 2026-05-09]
hardware/3d-print/stl/co2/co2_plate.stl
62.0 x 60.0 x 10.0

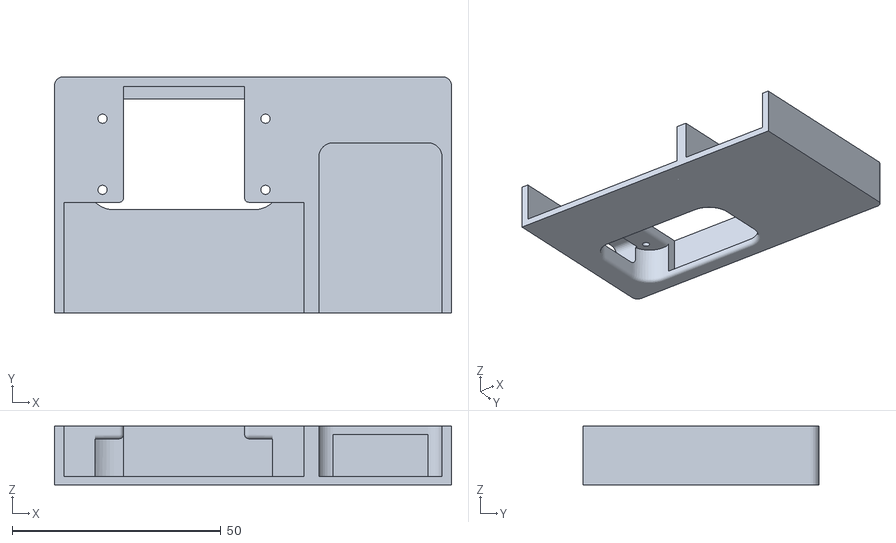
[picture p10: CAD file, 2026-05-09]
hardware/3d-print/stl/co2_o2/co2_o2_fascia.stl
95.0 x 56.5 x 14.0

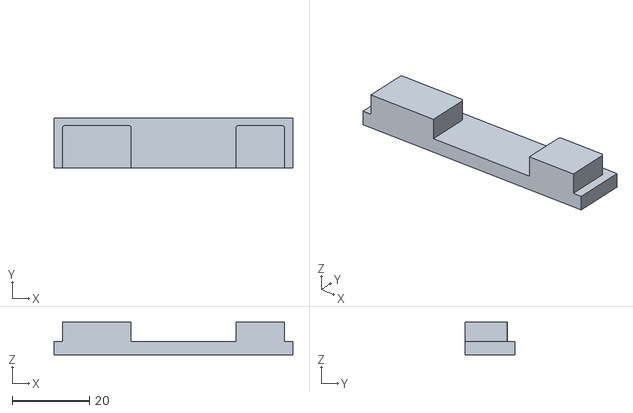
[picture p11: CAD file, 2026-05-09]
hardware/3d-print/stl/co2/co2_insert.stl
62.0 x 13.0 x 8.50

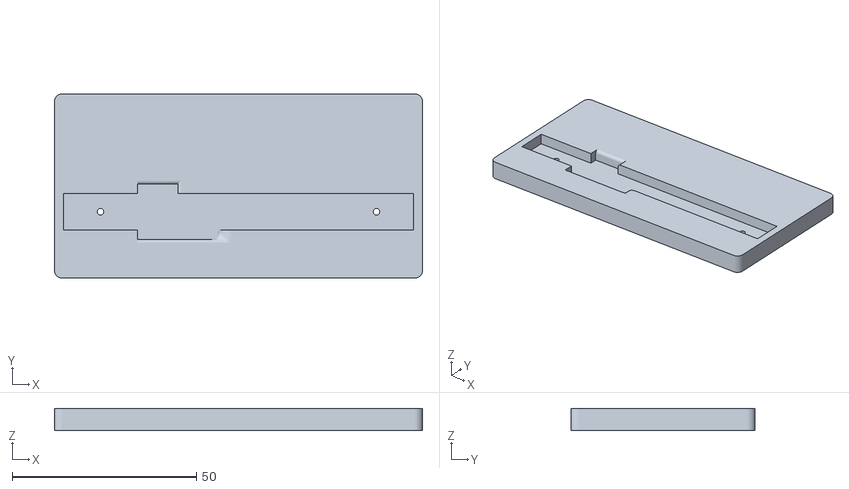
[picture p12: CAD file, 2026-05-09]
hardware/3d-print/stl/co2_o2/co_o2_base.stl
100.0 x 50.0 x 6.00

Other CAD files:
hardware/3d-print/fusion/co2/co2_base.f3d
hardware/3d-print/fusion/co2/co2_fascia.f3d
hardware/3d-print/fusion/co2/co2_insert.f3d
hardware/3d-print/fusion/co2/co2_plate.f3d
hardware/3d-print/fusion/co2_o2/co2_o2_base.f3d
hardware/3d-print/fusion/co2_o2/co2_o2_fascia.f3d
hardware/3d-print/fusion/co2_o2/co2_o2_insert.f3d
hardware/3d-print/fusion/co2_o2/co2_o2_plate.f3d

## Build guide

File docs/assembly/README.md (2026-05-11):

# Assembly Guide

This guide details the physical assembly and wiring of the gas monitor. Please ensure all 3D-printed parts are clean and free of support material before beginning. 

This guide covers both variants. Steps unique to the CO₂ + O₂ variant are marked **[CO₂+O₂ only]**.

> **Before You Start:**  
> Read through the complete guide before beginning. Have the [BOM](../../hardware/bom/) and [schematic](../../hardware/schematics/) open alongside this guide.

## Materials & Prep

**Required Tools:**

* Soldering iron & solder (fine tip recommended)
* Wire strippers/cutters
* M2 x 8mm screws (x4)
* Small Phillips head screwdriver

**Wire Preparation:**

Cut, strip and tin the following lengths of wire:

* **8.0 cm (x3):** For K30 GND, PWR, and TXD.
* **5.5 cm (x1):** For K30 RXD.
* **1.5 cm (x2):** For Logic Shifter LV-side data lines.
* **~4.0 cm (x1):** For Logic Shifter LV power line.
* **~2.0 cm (x1):** For Logic Shifter HV power line.
* **[CO₂+O₂ only]:** Four standard Dupont jumper wires for the SEN0322 (usually included with the connector on the device).

## Phase 1: Print enclosure
 
Print the plate, fascia and base from the files in `hardware/3d-print/stl/`. Use the settings in the [3D print README](../../hardware/3d-print/).

- Ensure to remove all of the support material from parts.
- **[CO₂+O₂ only]** there are some difficult to remove supports in the channel of the fascia where the SEN0322 cables are routed. I find a scalpel works well for this.

**[CO₂+O₂ only]** Use the `co2_o2/` STL files, which includes the SEN0322 sensor port.

##  Phase 2: Soldering & wiring

*(Please refer to the included schematics for visual pinout confirmation. It is recommend to color-code your wires: Red for 5V, Black for GND, and distinct colors for data lines).*

### 1. Wire the K30 Sensor

1. Solder **8 cm** wires to the **GND**, **PWR (G+)**, and **RXD** pads of the K30 sensor.
2. Solder the **5.5 cm** wire to the **TXD** pad of the K30.

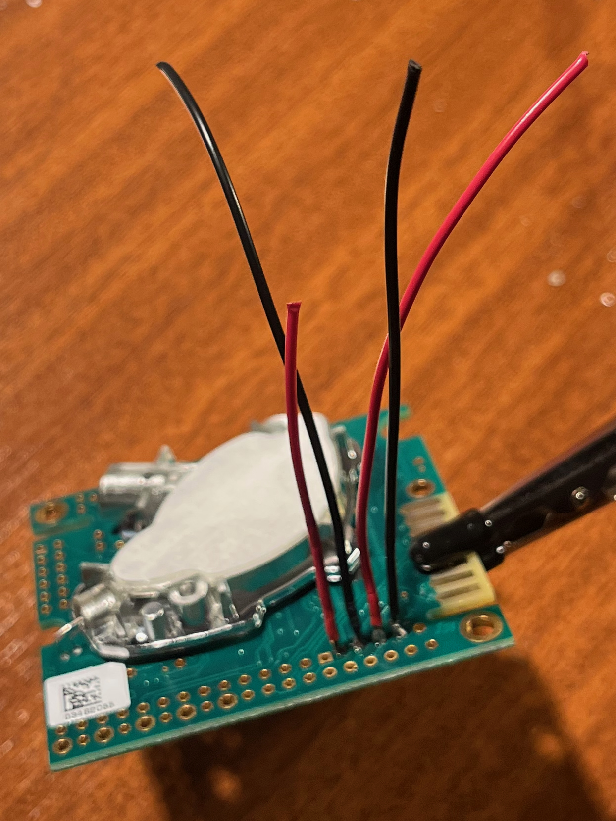
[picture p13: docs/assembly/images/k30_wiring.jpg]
K30 Sensor Wiring


### 2. Connect to the Logic Shifter

*The Logic Shifter protects the 3.3V ESP32 from the 5V signals of the K30.*

1. Solder the **5.5 cm RXD** wire coming from the K30 to the **H3** channel on the logic shifter.
1. Solder a **1.5 cm** wire to the **L3** pad.

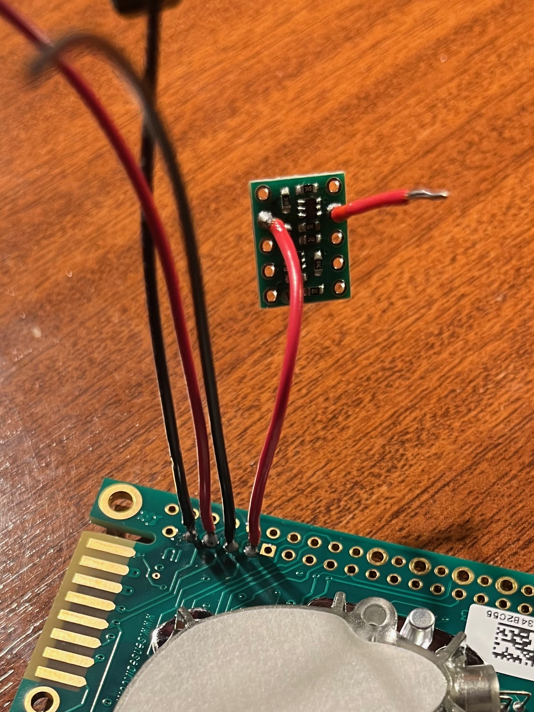
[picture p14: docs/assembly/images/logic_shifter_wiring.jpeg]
Logic Shifter Wiring


### 3. Wire the ESP32-S3
Now, connect everything back to the ESP32 microcontroller:

1. **Power:** Solder the K30 **PWR** wire to the ESP32 **VBUS (5V)** pin.
2. **Ground:** Solder the K30 **GND** wire to the ESP32 **GND** pin. 
3. **Data (TX to K30):** Solder the **1.5 cm L3** wire to the ESP32 **RXD** pin.
4. **Data (RX from K30):** Solder the **8 cm** wire to the ESP32 **TXD** pin.

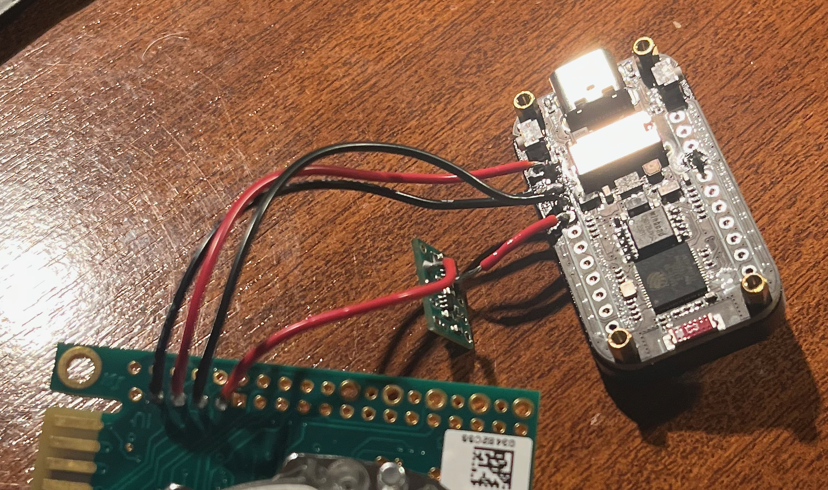
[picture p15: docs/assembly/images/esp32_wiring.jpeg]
ESP32 Wiring


### 4. Power the Logic Shifter
The logic shifter needs reference voltages to know how to translate the signals.

1. Solder the **~2 cm** wire from the ESP32 **VBUS (5V)** pin to the **HV** pad on the logic shifter.
2. Solder the **~4 cm** wire from the ESP32 **3V3 (3.3V)** pin to the **LV** pad on the logic shifter.

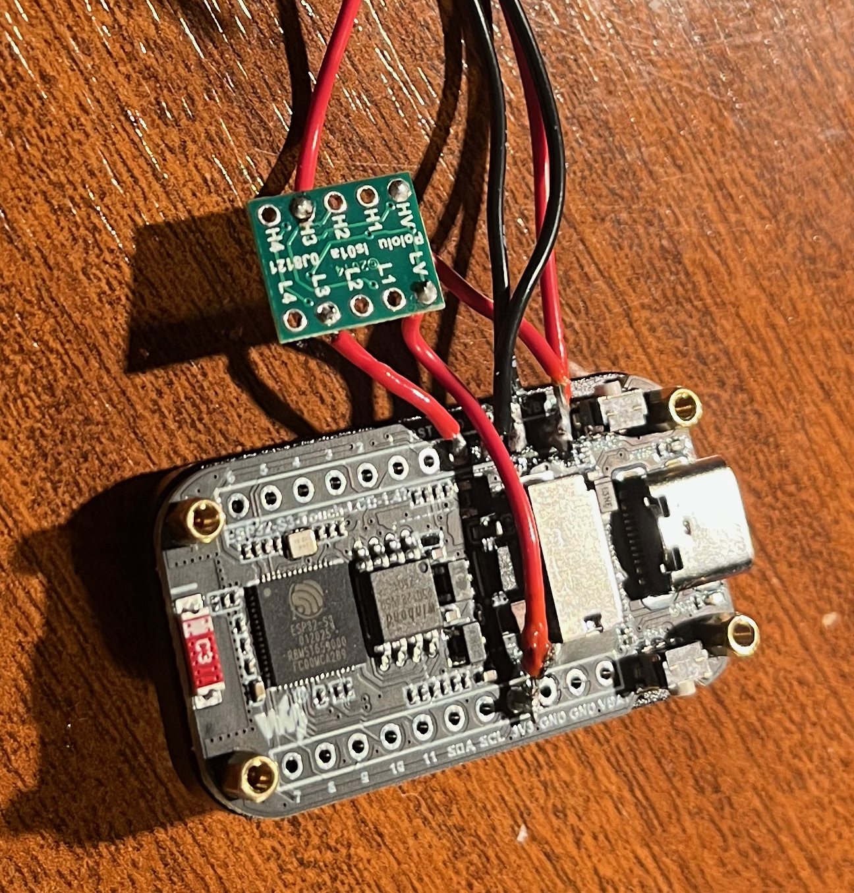
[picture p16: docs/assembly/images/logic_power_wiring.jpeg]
Logic Shifter Power Wiring


> **NOTE:**  
> This is a bodge, two wires share the same pad twice in this design. To get round this I solder a tinned piece of wire direcetly into the pad, then intertwine the two connecting wires (K30 PWR and HV PWR) and solder them to the exposed wire on the ESP32.

### 5. **[CO₂+O₂ only]** Prepare the SEN0322 O₂ Sensor
The SEN0322 comes ready to use but requires configuration:

1. Set the I²C address dial to **position 3** (address `0x73`) to avoid conflicting with the touchscreen controller. The dial is on the top face of the board; use a small flathead screwdriver. This is the default config on the sensor.
2. Connect the four wires:

    * **GND** → Common ground.
    * **VCC** → ESP32 **3V3 (3.3V)**
    * **SDA** → ESP32 **GPIO42**.
    * **SCL** → ESP32 **GPIO41**.

Oxygen Sensor Wiring

---

## Phase 3: Bench test

Before fitting anything into the enclosure, do a bench test with all components loose:

1. Insert the microSD card (FAT32 formatted).
2. Power the ESP32 via USB-C.
3. The display should light up and show the boot sequence. After warmup, the K30 should start returning readings.
4. **[CO₂+O₂ only]** The O₂ reading should appear after ~5 seconds.

Check the serial monitor in Arduino IDE (115200 baud) for any error messages. Common issues:

| Error Message | Likely Cause |
| :--- | :--- |
| **SD mount failed** | SD card not formatted as FAT32, or not inserted correctly. |
| **CO2 disconnected** | Level shifter wiring issue — check LV/HV reference connections and data routing. |
| **O₂ sensor not found** | Check SDA/SCL connections and ensure VCC is on 5V, not 3.3V. |
| **Display blank** | Backlight GPIO46 not driven — usually indicates wrong board selected in Arduino IDE. |

> ⚠️ **Do not proceed to enclosure assembly until all sensors are reading correctly.**

---

##  Phase 4: Physical assembly

### 1. Mount the ESP32 Fascia

* Carefully slide the ESP32-S3 screen-first through the slot in the 3D-printed **Fascia** part.
* Gently route and line up the attached cables so they point toward the back.
* **[CO₂+O₂ only]** Pass the SEN0322 connector through the slot in the fascia into the right hand side.

Oxygen Sensor Assembly

### 2a. **[CO₂+O₂ only]**: Mount the oxygen sensor on the plate

* Push the included hexagonal standoffs into the cutouts on the plate.
* Use the included fixings to attach the sensor to the plate, ensuring the calibration button aligns with the cutout in the plate.

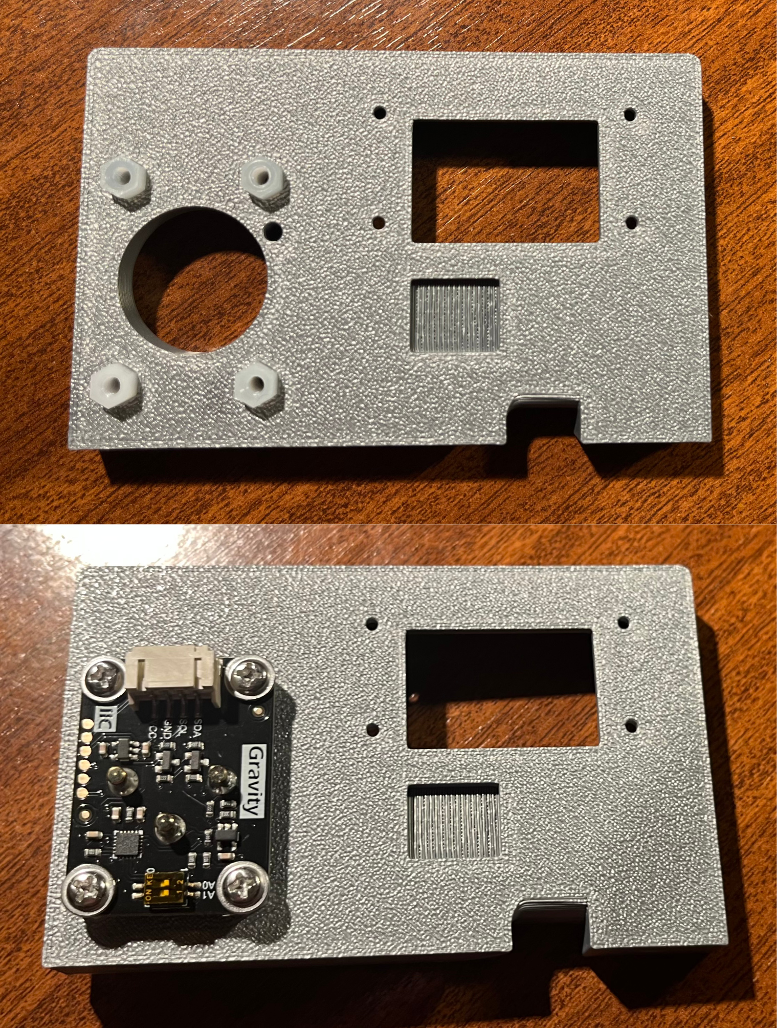
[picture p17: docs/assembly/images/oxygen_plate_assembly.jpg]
Oxygen Plate Assembly


> **NOTE:**  
> Depending on the tolerances of your print, you may need to shave down (using a sharp blade) the hexagonal edges on end of each of the standoffs so that they can be push fit into the plate.

### 2. Secure the Core Plates

* **[CO₂+O₂ only]** connect the SEN0322 connector to the sensor.
* Offer up the **Plate** part to the back of the Fascia.
* Line up the holes for the M2 screws so they pass through the Fascia, the ESP32 mounting holes, and into the Plate.
* Secure the assembly using the four **M2x8mm screws**. Do not overtighten, as this can crack the plastic or the ESP32 PCB.

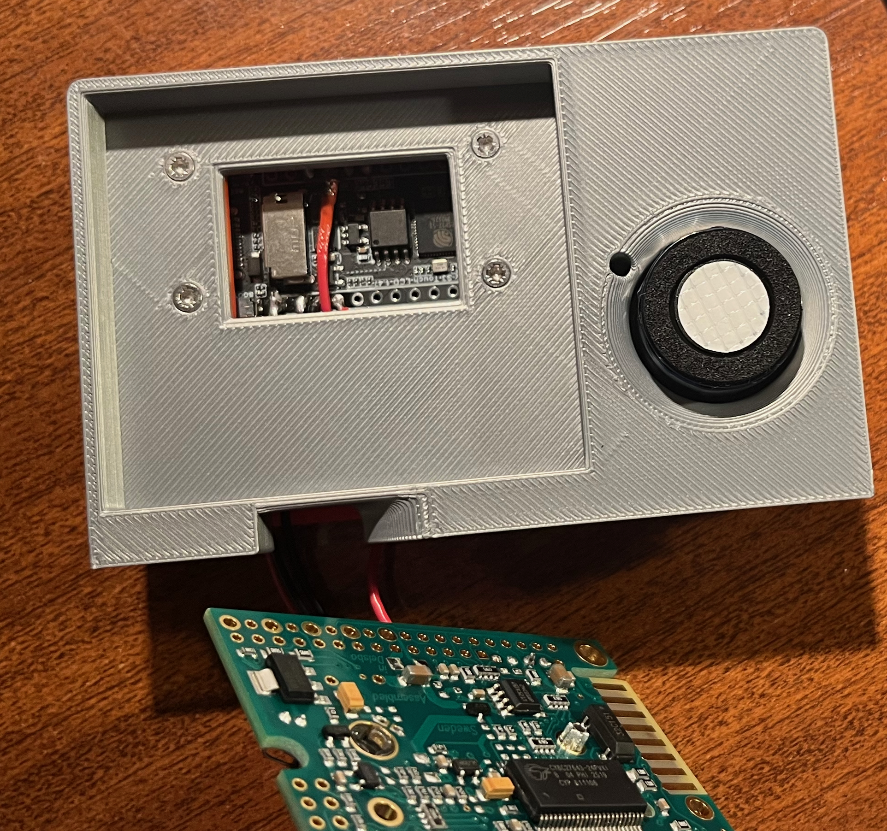
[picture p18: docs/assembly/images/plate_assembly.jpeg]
Plate Assembly


### 3. Seat the Logic Shifter & Sensors

* Position the Logic Shifter snugly into its dedicated cutout on the back of the Plate.
* Route the wiring to pass cleanly underneath using the bottom cutout.
* Take the wired **K30 sensor** and press it lightly into the Plate. This is a friction/push-fit design and should seat firmly.

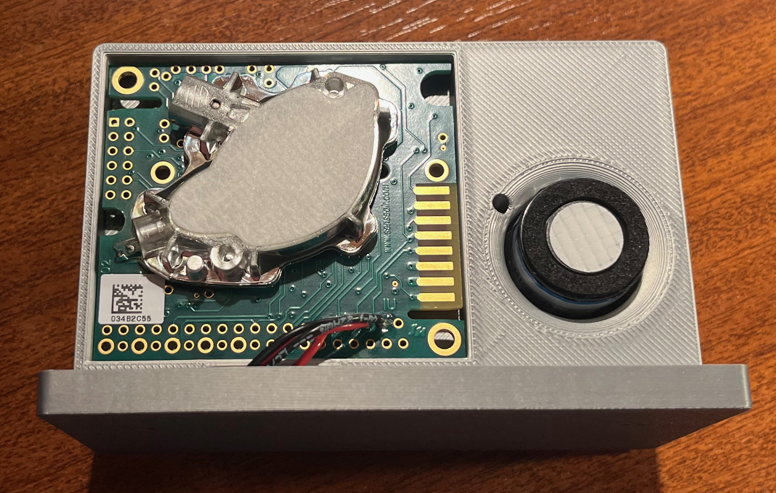
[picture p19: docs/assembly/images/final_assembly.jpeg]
Final Assembly


### 4. Attach the Base
Choose your preferred finish for the bottom of the device:

* **The Base:** Attach this push-fit part if you want the device to have a stand-like appearance.
* **The Insert:** Use this part if you prefer a flush, flat-bottom, low-profile finish.

Finished Assembly

---

##  Phase 5: Final Power-on & Configuration

1. Power via USB-C. Confirm the display shows the correct boot sequence and readings.
2. Connect to the sensor's WiFi hotspot on your phone/laptop and navigate to `192.168.4.1`.
3. Verify the web interface loads and shows the same readings as the physical device display.
4. Use the Web UI Settings page to configure the `deviceName`, `location`, and target WiFi credentials for the intended installation location.

---

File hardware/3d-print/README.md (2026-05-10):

# 3D Print Files

Enclosure files for both sensor variants. Source files are Autodesk Fusion projects; STLs are provided for direct slicing.

```
3d-print/
├── README.md           (this file)
├── fusion/             # Autodesk Fusion source projects (.f3d)
│   ├── co2_only/
│   └── co2_o2/
├── stl/
│   ├── co2_only/
│   │   ├── co2_base.stl
│   │   └── co2_fascia.stl
│   │   └── co2_plate.stl
│   │   └── co2_insert.stl
│   └── co2_o2/
│   │   ├── co2_o2_base.stl
│   │   └── co2_o2_fascia.stl
│   │   └── co2_o2_plate.stl
│   │   └── co2_o2_insert.stl
└── renders/            # Reference images
```

---

## Print Settings

These settings were used for production units on Bambu Labs printers. Other configurations will work but may require tolerance adjustments.

| Setting | Recommended value |
|---|---|
| Material | PLA |
| Layer height | 0.2 mm |
| Infill | 20% gyroid |
| Perimeters / walls | 3 |
| Top/bottom layers | 4 |
| Supports | Tree |
| Bed adhesion | Brim (base only)  |
| Nozzle temp (PETG) | 235°C |
| Bed temp (PETG) | 60°C |

### Material notes

**PETG** is preferred for growth chamber use — it tolerates higher humidity and temperatures than PLA without deforming. It is also slightly more flexible, which helps with clip-fit lids.

**PLA** works fine for ambient lab environments. Avoid if the enclosure will be exposed to sustained temperatures above 50°C or high humidity condensation.

---

## Enclosure Design
Each sensor enclosure consists of two main parts and an additional part for the base which can be either a standard base (self-supporting) or a low-profile insert.

### Plate
The plate contains the main recess for the push-fit of the K30 as well as the 4 mounting points for the ESP32 board which also serve to connect the fascia to the plate. For the CO₂+O₂ variant the plate also contains cutouts for push-fit of the SEN0322 standoffs that are used to mount the sensor, as well as a cutout for the SEN0322 sensor body:
- K30 sensor mounting recess
- Routing for the wiring from the ESP32 board to the K30.
- **CO₂+O₂ variant only:** cutouts for push-fit of the SEN0322 standoffs
- **CO₂+O₂ variant only:** additional circular port on the side for the SEN0322 body; the electrical connections pass through internally

### Fascia

The fascia is attached to the plate using the 4x M2x8mm screws and contains cutouts for the display, the USB-C charger Features:
- Display aperture (the Waveshare board's display faces upward through the lid)
- Touch-accessible surface over the display area
- **CO₂+O₂ variant only:** routing for the SEN0322 wiring to the ESP32

### Bases
The base is either a standard base (self-supporting) or a low-profile insert. Both operate on push-fit tolerances, where the insert leaves a flush finish but may not support the sensor standing upright and is intended for alternative mounting options.

---

## Dimensional Notes

- The display aperture is sized for the Waveshare ESP32-S3 1.47" display (172×320px panel, 35.5×71.0mm active area)
- K30 dimensions: 57×57×15mm — the mounting recess matches this with 0.3mm clearance
- SEN0322 dimensions: 22×27×13mm — the side port matches the 22×13mm profile
---

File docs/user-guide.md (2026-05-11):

# User Guide

This guide covers day-to-day operation of the gas monitoring system for lab members. For build and setup instructions see the assembly guide and [firmware README](../firmware/README.md).

---

## Contents

1. [System Overview](#1-system-overview)
2. [The Grafana Dashboard](#2-the-grafana-dashboard)
3. [Individual Sensor Web Interface](#3-individual-sensor-web-interface)
4. [Time Synchronisation](#4-time-synchronisation)
5. [Calibration](#5-calibration)
6. [Downloading Data](#6-downloading-data)
7. [Troubleshooting](#7-troubleshooting)

---

## 1. System Overview

The monitoring network has three tiers:

```
ESP32 sensor units          Raspberry Pi hub          Grafana Cloud
(one per chamber)    ──►   (GasMonitor WiFi)   ──►   (remote dashboard)
                            InfluxDB (local)
                            
Windows/Linux laptop ──►   (GasMonitor WiFi)
(Minir-5 + K30 1%)
```

**Each ESP32 sensor unit:**

- Measures CO₂ every 1–60 seconds (configurable)
- Optionally measures O₂ (combined units only)
- Displays live readings on a 1.47" touchscreen
- Logs data to an onboard SD card (monthly CSV files, indefinite retention)
- Hosts its own web interface at `192.168.4.1` when you connect to its hotspot
- Pushes data to the Raspberry Pi for central monitoring

**The Raspberry Pi hub:**

- Broadcasts the `GasMonitor` WiFi network
- Receives data from all sensors
- Forwards to Grafana Cloud (14-day retention)
- Provides automatic time sync to sensors on connection

**The laptop (mixing bottle monitors only):**

- Reads the Minir-5 (orange bottle, 1–5% CO₂) and K30 1% (clear bottle, ambient CO₂) via USB
- Pushes readings to the Pi via GasMonitor WiFi
- Displays the Grafana dashboard full-screen for room-level monitoring

---

## 2. The Grafana Dashboard

### Accessing the dashboard

**In the growth room:** The laptop displays the dashboard full-screen at all times. No login required.

**From your own device:**

- Open the dashboard URL (ask the lab manager for the link)
- Must be on the university network, university WiFi, or VPN

**As a home screen app (recommended):**

*Chrome (desktop or Android):*

1. Open the dashboard URL in Chrome
2. Click the three-dot menu → **Cast, save and share** → **Install as app**
3. Click **Install** — the dashboard appears as an app icon

*Safari (iPhone / iPad):*

1. Open the dashboard URL in Safari
2. Tap the **Share** button (square with arrow)
3. Tap **Add to Home Screen** → **Add**
4. Opens as a full-screen app without browser toolbars

### What the dashboard shows

- All sensors displayed as separate panels
- Mixing bottle sensors (Minir-5 and K30 1%) at the top, colour-coded by bottle colour (orange and clear)
- Chamber sensors below
- Up to 14 days of history
- Adjustable time window using the time picker in the top-right corner of the Grafana page

### Dashboard vs local interface

| Feature | Grafana dashboard | Local web interface (192.168.4.1) |
|---|---|---|
| All sensors at once | ✓ | One sensor only |
| Remote access | ✓ | Only when connected to sensor hotspot |
| History | 14 days | Up to 10,000 readings in browser; full history on SD card |
| Download CSV | — | ✓ |
| Calibration | — | ✓ |
| Settings | — | ✓ |
| Works without Pi | — | ✓ |

---

## 3. Individual Sensor Web Interface

Each sensor has its own web interface, accessible by connecting to its WiFi hotspot.

### Connecting

1. On your phone or laptop, open WiFi settings
2. Connect to the sensor's network — the SSID is the device name (e.g. `Bournemouth`, `Chamber 4`)
3. Open a browser and go to `192.168.4.1`

> **Phone users:** disable mobile data if the page doesn't load — your phone may be using mobile data instead of the sensor WiFi.

### Reading view

The main page shows:

- Live CO₂ reading in ppm with a trend arrow (▴ rising / ▾ falling / · stable)
- Live O₂ reading in % with trend arrow (combined units only)
- Last calibration date and type
- A graph of recent readings for the configured window

### Graph

The graph shows real timestamps (HH:MM) on the x-axis once the device has been time-synced. The time window is configurable in Settings. Tap the graph area on the device touchscreen to switch between CO₂ and O₂ graph pages (combined units).

### Settings

Navigate to **Settings** in the web interface to change:

| Setting | Description |
|---|---|
| Graph window | Time period shown on device and web graph (1 min to 96 hours) |
| Read interval | How often the sensor takes a measurement (1s to 30 min) |
| Device name | Shown on screen and used as the sensor ID in Grafana |
| Location | Location tag in Grafana |
| WiFi SSID | The sensor's own hotspot network name |
| WiFi password | The sensor's own hotspot password |

> WiFi changes require a device reboot to take effect. Make a note of any new credentials before saving.

### Calibration log

The web interface shows the three most recent calibration events — type, date/time, and CO₂ reading at the time. A full log is stored on the SD card as `cal_log.csv`.

---

## 4. Time Synchronisation

The sensor hardware has no real-time clock. Time must be provided after each restart.

### Automatic (Pi connected — normal operation)

When a sensor starts and connects to `GasMonitor` WiFi, the Pi automatically provides the current time. No user action required. A green dot appears on the device screen to confirm the Pi connection.

### Manual (Pi unavailable)

If the Pi is offline or the sensor is being used away from the growth room, the sensor displays a splash screen:

```
TIME SYNC REQUIRED
1. Connect to WiFi: [sensor SSID]
2. Open in browser: 192.168.4.1
```

To sync time:

1. Connect to the sensor's own WiFi hotspot
2. Open `192.168.4.1` in a browser
3. Time syncs automatically from your device — the splash screen clears

> **Data during unsync period:** Readings are still recorded to a `fallback.csv` file on the SD card. Once time is synced, this file is automatically backdated and merged into the correct monthly log. No data is lost.

---

## 5. Calibration

### CO₂ sensor (K30) — when to calibrate

Calibrate the K30 if:

- Readings appear consistently offset from expected values
- The sensor has been stored for a long period
- As part of routine quality control

### Calibration methods

#### 0 ppm calibration (recommended)

The most reliable method. Expose the sensor to a gas containing 0 ppm CO₂ and calibrate to zero.

**Suitable gas sources available in the growth room:**

- Pure nitrogen (N₂)
- 21% O₂ / 79% N₂ (0 ppm CO₂) gas mix plumbed into the growth room

**Procedure:**

1. Connect the sensor to N₂ or the zero gas mix
2. Wait for the reading to stabilise — at least 2–3 minutes
3. Connect to the sensor's web interface and click **Calibrate → 0 ppm**
4. Confirm in the dialog
5. Wait for calibration to complete (~10 seconds)

#### 400 ppm calibration (use with caution)

> ⚠️ **Warning — departmental compressed air line:** The compressed air supply takes outdoor air through desiccation and delivers it at approximately 400 ppm CO₂ on average. However, outdoor CO₂ varies diurnally and with atmospheric conditions, and the compression/desiccation process can shift concentrations. **The actual concentration at any given moment may be ±100 ppm from 400 ppm.** Do not use this supply for 400 ppm calibration without first verifying the concentration independently.

**Preferred method — outdoor calibration:**

1. Power the sensor from a USB battery pack or laptop
2. Take the sensor outdoors, away from building exhausts and busy roads
3. Allow 5 minutes for the reading to stabilise
4. Connect to the sensor's web interface and click **Calibrate → 400 ppm**
5. Confirm in the dialog

### Confirming calibration

After any calibration, allow 2–3 minutes for the reading to fully stabilise, then verify against a known reference.

### O₂ sensor (SEN0322) — combined units only

The O₂ sensor does not require calibration via the web interface. If recalibration is needed:

1. Take the sensor outdoors to clean air (20.9% O₂)
2. Hold the **physical button on the back of the SEN0322 board** until the reading stabilises at ~20.9%

Under normal laboratory conditions O₂ recalibration is rarely necessary. The sensor has a lifetime of approximately **2 years** — readings drifting consistently low or becoming unstable indicate the cell needs replacement.

### Mixing bottle analysers (Minir-5 and K30 1%) — experienced users only

These sensors are calibrated using dedicated Python GUI tools on the laptop. See the laptop bridge README for full instructions. The GasLab software is no longer used.

**Important:** Stop the relevant pusher script before running the calibration tool, and restart it afterwards.

---

## 6. Downloading Data

### From the web interface

1. Connect to the sensor's WiFi hotspot
2. Open `192.168.4.1`
3. Scroll to **Logs**
4. Click **Download** next to the month you want
5. A CSV file will download to your device

### CSV file format

```
datetime,uptime_s,co2_ppm[,o2_pct]
2026-05-10 14:23:01,3601,842[,20.91]
```

- `datetime` — UTC timestamp (ISO 8601)
- `uptime_s` — seconds since last device restart
- `co2_ppm` — CO₂ concentration in ppm
- `o2_pct` — O₂ percentage (combined units only)

### Storage

Log files are stored indefinitely on the SD card. At a 5-second read interval the card has capacity for over 20 years of continuous data. Files are never automatically deleted.

---

## 7. Troubleshooting

| Symptom | Likely cause | Action |
|---|---|---|
| Splash screen asking to sync time | Pi unavailable at startup | Connect to sensor hotspot → open 192.168.4.1 |
| Sensor not in Grafana | Not connected to GasMonitor WiFi | Check green dot on device screen; check Pi is powered |
| `CO₂ disconnected` on screen | K30 not responding | Power-cycle the sensor; check K30 cable |
| O₂ shows `--` | SEN0322 not detected at boot | Power-cycle; check VCC is on 5V not 3.3V |
| O₂ readings drifting low | Electrochemical cell near end of life | Replace SEN0322 (~2 year lifetime) |
| Web interface won't load at 192.168.4.1 | Not connected to sensor hotspot | Connect to sensor WiFi and disable mobile data |
| Settings not saved after reboot | SD card missing or not FAT32 | Check SD card is seated; reformat as FAT32 if needed |
| Missing months in CSV log | Device ran without time sync | Check SD card for `fallback.csv` — data may be there, backdated on next sync |
| Mixing bottle sensors absent from Grafana | Laptop powered off or scripts stopped | Check laptop is on and logged in; restart pusher scripts if closed |
| Readings offset after calibration | Calibration performed with unstable reading | Wait for full stabilisation (2–3 min) and recalibrate |
| 400 ppm calibration gives wrong result | Departmental air line CO₂ variation | Use outdoor calibration or N₂/zero gas instead |

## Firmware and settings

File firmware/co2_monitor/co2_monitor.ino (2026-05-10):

#include <Arduino_GFX_Library.h>
#include <Wire.h>
#include <WiFi.h>
#include <WebServer.h>
#include "esp_lcd_touch_axs5106l.h"
#include <SD_MMC.h>
#include <HTTPClient.h>

// --- Pi Network & Sensor Config ---
const char* PI_SSID = "GasMonitor";
const char* PI_PASS = "set yours here";
const char* PI_HOST = "192.168.50.1";
const int   PI_PORT = 5000;
char sensorID[32]   = "sensor1";   // configurable via web UI
char location[32]   = "chamber1";  // configurable via web UI
bool piConnected = false; // Tracks if we are talking to the Pi
long localTimeOffset = 0;

// ============================================================
//  CO2 Monitor — Display + Touch Cal + WiFi Dashboard
// ============================================================

// --- Display ---
#define GFX_BL   46
#define LCD_RST  40

Arduino_DataBus *bus = new Arduino_ESP32SPI(45, 21, 38, 39);
Arduino_GFX *gfx = new Arduino_ST7789(
  bus, LCD_RST, 0, false,
  172, 320,
  34, 0, 34, 0);

// --- Touch ---
#define Touch_SDA  42
#define Touch_SCL  41
#define Touch_RST  47
#define Touch_INT  48

// --- K30 UART ---
#define RX_PIN 44
#define TX_PIN 43
HardwareSerial K30Serial(1);

// --- WiFi AP ---
const char* AP_SSID = "CO2Monitor";
const char* AP_PASS = "co2monitor123";
WebServer server(80);

// --- Timing ---
#define WARMUP_MS_DEFAULT     10000
#define READ_INTERVAL_DEFAULT 6000
#define CO2_GOOD_DEFAULT      450

unsigned long WARMUP_MS    = WARMUP_MS_DEFAULT;
unsigned long READ_INTERVAL = READ_INTERVAL_DEFAULT;
int           CO2_GOOD      = CO2_GOOD_DEFAULT;
int flagIndex = 0;

#define CMD_TIMEOUT   2000

#define CAL_LOG_FILE "/cal_log.csv"
#define SETTINGS_FILE "/settings.json"
#define CAL_FILE "/lastcal.txt"

// --- History buffer ---
#define HISTORY_SIZE  100000
int* co2History    = nullptr;
unsigned long* timeHistory  = nullptr;
int           historyIndex  = 0;
int           historyCount  = 0;
unsigned long GRAPH_WINDOW_S = 1800;

// --- K30 commands ---
byte K30_READ[7]   = {0xFE, 0x44, 0x00, 0x08, 0x02, 0x9F, 0x25};
byte K30_UNLOCK[8] = {0xFE, 0x06, 0x00, 0x00, 0x00, 0x00, 0x9D, 0xC5};
byte CAL_400[8]    = {0xFE, 0x06, 0x00, 0x01, 0x7C, 0x06, 0x6C, 0xC7};
byte CAL_0[8]      = {0xFE, 0x06, 0x00, 0x01, 0x7C, 0x07, 0xAD, 0x07};
byte ABC_OFF[8]    = {0xFE, 0x06, 0x00, 0x1F, 0x00, 0x00, 0xAC, 0x03};

// --- Colours ---
#define COL_TITLE      0x07FF
#define COL_UNIT       0x7BEF
#define COL_GOOD       0x07e0
#define COL_WARN       0xffe0
#define COL_BAD        0xf800
#define COL_WHITE      RGB565_WHITE
#define COL_BTN        0x2945
#define COL_BTN_ACTIVE 0x07FF

// --- Web UI Palette translated to RGB565 ---
#define COL_BG       0x10C3  // #15181c (Main dark background)
#define COL_CO2      0x073F  // #00e5ff (Cyan/Neon Blue primary accent)
#define COL_TEXT     0xFFFF  // #ffffff (White text)
#define COL_MUTED    0x7BEF  // #777777 (Muted gray for units and axes)
#define COL_BORDER   0x2945  // #2a2a2a (Subtle divider lines)
#define COL_DANGER   0xF206  // #f44336 (Red for delete/danger)
#define BLACK   0x0000
#define WHITE   0xFFFF
#define GREEN   0x07E0
#define RED     0xF800
#define BLUE    0x001F

// --- Layout (landscape 320x172) ---
#define SCREEN_W   320
#define SCREEN_H   172
#define TITLE_H      0
#define BAR_H        4
#define MAIN_X       0
#define MAIN_W       SCREEN_W

// --- State ---
bool          calibrating       = false;
int           lastCO2           = 0;
unsigned long lastReadTime      = 0;
unsigned long startTime         = 0;
unsigned long browserTimeOffset = 0;
unsigned long readDuration = 0;

// --- View mode ---
int           graphMode         = 0;  // 0=reading, 1=CO2 graph
unsigned long lastTouchTime     = 0;
#define TOUCH_DEBOUNCE_MS 400

// --- Min/max tracking ---
int           sessionMin        = 32767;
int           sessionMax        = -32768;

// --- Calibrant logs ---
String lastCalType = "";
unsigned long lastCalUnix = 0;

// --- SD Card ---
bool          sdAvailable       = false;
const char*   SD_FILE           = "/co2_log.csv";
bool timeSynced = false;
bool warningDrawn = false; // Prevents the screen from flickering by drawing the warning only once

int consecutiveFailures = 0;
int prevCO2 = -1;

// 12h min/max ring buffer
#define MINMAX_WINDOW_S 43200UL  // 12 hours
int co2Min12h = 32767;
int co2Max12h = -32768;

// --- Device name ---
char deviceName[32]  = "CO2 Monitor";
char apSSID[32]      = "CO2Monitor";
char apPass[32]      = "co2monitor123";


void getLogFilename(char* out, size_t len) {
  if (browserTimeOffset == 0) {
    strncpy(out, "/fallback.csv", len);
    return;
  }
  unsigned long now = browserTimeOffset + (millis() - startTime) / 1000;
  getLogFilenameFromUnix(now, out, len);
}

void getLogFilenameFromUnix(unsigned long unix, char* out, size_t len) {
  unsigned long t = unix / 60 / 60 / 24;
  unsigned long days = t;
  int year = 1970;
  while (true) {
    bool leap = (year%4==0 && (year%100!=0 || year%400==0));
    int diy = leap ? 366 : 365;
    if (days < (unsigned long)diy) break;
    days -= diy; year++;
  }
  bool leap = (year%4==0 && (year%100!=0 || year%400==0));
  int monthDays[] = {31,leap?29:28,31,30,31,30,31,31,30,31,30,31};
  int month = 0;
  while (days >= (unsigned long)monthDays[month]) { days -= monthDays[month]; month++; }
  snprintf(out, len, "/%04d-%02d.csv", year, month+1);
}


// ============================================================
//  DISPLAY INIT
// ============================================================

void lcd_reg_init(void) {
  static const uint8_t init_operations[] = {
    BEGIN_WRITE,
    WRITE_COMMAND_8, 0x11,
    END_WRITE,
    DELAY, 120,

    BEGIN_WRITE,
    WRITE_C8_D16, 0xDF, 0x98, 0x53,
    WRITE_C8_D8,  0xB2, 0x23,

    WRITE_COMMAND_8, 0xB7,
    WRITE_BYTES, 4,
    0x00, 0x47, 0x00, 0x6F,

    WRITE_COMMAND_8, 0xBB,
    WRITE_BYTES, 6,
    0x1C, 0x1A, 0x55, 0x73, 0x63, 0xF0,

    WRITE_C8_D16, 0xC0, 0x44, 0xA4,
    WRITE_C8_D8,  0xC1, 0x16,

    WRITE_COMMAND_8, 0xC3,
    WRITE_BYTES, 8,
    0x7D, 0x07, 0x14, 0x06, 0xCF, 0x71, 0x72, 0x77,

    WRITE_COMMAND_8, 0xC4,
    WRITE_BYTES, 12,
    0x00, 0x00, 0xA0, 0x79, 0x0B, 0x0A, 0x16, 0x79, 0x0B, 0x0A, 0x16, 0x82,

    WRITE_COMMAND_8, 0xC8,
    WRITE_BYTES, 32,
    0x3F, 0x32, 0x29, 0x29, 0x27, 0x2B, 0x27, 0x28, 0x28, 0x26, 0x25, 0x17,
    0x12, 0x0D, 0x04, 0x00, 0x3F, 0x32, 0x29, 0x29, 0x27, 0x2B, 0x27, 0x28,
    0x28, 0x26, 0x25, 0x17, 0x12, 0x0D, 0x04, 0x00,

    WRITE_COMMAND_8, 0xD0,
    WRITE_BYTES, 5,
    0x04, 0x06, 0x6B, 0x0F, 0x00,

    WRITE_C8_D16, 0xD7, 0x00, 0x30,
    WRITE_C8_D8,  0xE6, 0x14,
    WRITE_C8_D8,  0xDE, 0x01,

    WRITE_COMMAND_8, 0xB7,
    WRITE_BYTES, 5,
    0x03, 0x13, 0xEF, 0x35, 0x35,

    WRITE_COMMAND_8, 0xC1,
    WRITE_BYTES, 3,
    0x14, 0x15, 0xC0,

    WRITE_C8_D16, 0xC2, 0x06, 0x3A,
    WRITE_C8_D16, 0xC4, 0x72, 0x12,
    WRITE_C8_D8,  0xBE, 0x00,
    WRITE_C8_D8,  0xDE, 0x02,

    WRITE_COMMAND_8, 0xE5,
    WRITE_BYTES, 3,
    0x00, 0x02, 0x00,

    WRITE_COMMAND_8, 0xE5,
    WRITE_BYTES, 3,
    0x01, 0x02, 0x00,

    WRITE_C8_D8, 0xDE, 0x00,
    WRITE_C8_D8, 0x35, 0x00,
    WRITE_C8_D8, 0x3A, 0x05,

    WRITE_COMMAND_8, 0x2A,
    WRITE_BYTES, 4,
    0x00, 0x22, 0x00, 0xCD,

    WRITE_COMMAND_8, 0x2B,
    WRITE_BYTES, 4,
    0x00, 0x00, 0x01, 0x3F,

    WRITE_C8_D8, 0xDE, 0x02,

    WRITE_COMMAND_8, 0xE5,
    WRITE_BYTES, 3,
    0x00, 0x02, 0x00,

    WRITE_C8_D8, 0xDE, 0x00,
    WRITE_C8_D8, 0x36, 0x00,
    WRITE_COMMAND_8, 0x21,
    END_WRITE,

    DELAY, 10,

    BEGIN_WRITE,
    WRITE_COMMAND_8, 0x29,
    END_WRITE
  };
  bus->batchOperation(init_operations, sizeof(init_operations));
}

// ============================================================
//  DISPLAY HELPERS
// ============================================================
void drawTrendIcon(int x, int y, int size, const char* trend, uint16_t color) {
  gfx->setTextColor(color);

  if (trend[0] == '^') {
    // ▲ Up triangle
    gfx->fillTriangle(
      x, y,                     // top
      x - size, y + size,      // bottom left
      x + size, y + size,      // bottom right
      color
    );
  }
  else if (trend[0] == 'v') {
    // ▼ Down triangle
    gfx->fillTriangle(
      x, y + size,             // bottom
      x - size, y,             // top left
      x + size, y,             // top right
      color
    );
  }
  else {
    // — Stable (small horizontal line)
    gfx->drawFastHLine(x - size, y + size/2, size * 2, color);
  }
}

void updateMinMax12h() {
  if (historyCount == 0) return;

  co2Min12h = 32767;
  co2Max12h = -32768;

  // 1. Find the timestamp of the very last reading
  int lastIndex = (historyIndex - 1 + HISTORY_SIZE) % HISTORY_SIZE;
  unsigned long tLast = timeHistory[lastIndex];
  
  // 2. Calculate the cutoff for 12 hours ago
  unsigned long windowStart = (tLast > MINMAX_WINDOW_S) ? tLast - MINMAX_WINDOW_S : 0;

  // 3. Iterate through valid history
  for (int i = 0; i < historyCount; i++) {
    int idx = (historyIndex - historyCount + i + HISTORY_SIZE) % HISTORY_SIZE;
    
    // Skip readings older than 12 hours
    if (timeHistory[idx] < windowStart) continue;

    // Check min/max
    int v = co2History[idx];
    if (v < co2Min12h) co2Min12h = v;
    if (v > co2Max12h) co2Max12h = v;
  }

  // 4. Fallback if no valid data was found
  if (co2Min12h == 32767) {
    co2Min12h = 0;
    co2Max12h = 0;
  }
}

void drawButton(int x, int y, int w, int h, const char* l1, const char* l2, const char* l3, uint16_t bg, uint16_t fg) {
  // Background — leave a small margin for rounded look
  gfx->fillRect(x, y, w, h, COL_BG);
  gfx->fillRoundRect(x + 8, y + 6, w - 16, h - 12, 6, bg);
  gfx->drawRoundRect(x + 8, y + 6, w - 16, h - 12, 6, 0x3186);

  gfx->setTextColor(fg);
  int lineH1 = 8;   // size 1
  int lineH2 = 16;  // size 2
  int totalH = lineH1 + lineH2 + lineH1 + 4;
  int startY = y + 6 + ((h - 12) - totalH) / 2;

  gfx->setTextSize(1);
  int tw = strlen(l1) * 6;
  gfx->setCursor(x + (w - tw) / 2, startY);
  gfx->print(l1);

  gfx->setTextSize(2);
  tw = strlen(l2) * 12;
  gfx->setCursor(x + (w - tw) / 2, startY + lineH1 + 2);
  gfx->print(l2);

  gfx->setTextSize(1);
  tw = strlen(l3) * 6;
  gfx->setCursor(x + (w - tw) / 2, startY + lineH1 + lineH2 + 4);
  gfx->print(l3);
}

void drawFlag(int x, int y) {
  int fw = 18;
  int fh = 12;
  
  if (flagIndex == 0) {
    // 🇲🇱 Mali
    gfx->fillRect(x, y, fw/3, fh, 0x25a8);
    gfx->fillRect(x + fw/3, y, fw/3, fh, 0xfe84);
    gfx->fillRect(x + 2*(fw/3), y, fw/3, fh, 0xc8c6);
  } 
  else if (flagIndex == 1) {
    // 🇰🇷 South Korea
    gfx->fillRect(x, y, fw, fh, 0xFFFF);
    gfx->fillCircle(x + fw/2, y + fh/2, 3, 0xF800);
    for(int i = -3; i <= 3; i++) {
      for(int j = 0; j <= 3; j++) {
        if (i*i + j*j <= 9) gfx->drawPixel(x + fw/2 + i, y + fh/2 + j, 0x001F);
      }
    }
    gfx->drawLine(x+2, y+2, x+4, y+4, 0x0000);
    gfx->drawLine(x+fw-3, y+2, x+fw-5, y+4, 0x0000);
    gfx->drawLine(x+2, y+fh-3, x+4, y+fh-5, 0x0000);
    gfx->drawLine(x+fw-3, y+fh-3, x+fw-5, y+fh-5, 0x0000);
  } 
  else if (flagIndex == 2) {
    // 🏴󠁧󠁢󠁥󠁮󠁧󠁿 England
    gfx->fillRect(x, y, fw, fh, 0xFFFF);
    gfx->fillRect(x + fw/2 - 1, y, 2, fh, 0xF800);
    gfx->fillRect(x, y + fh/2 - 1, fw, 2, 0xF800);
  } 
  else if (flagIndex == 3) {
    // 🇧🇷 Itaim Bibi
    uint16_t green = 0x24c6;
    uint16_t white = 0xFFFF;
    uint16_t grey  = 0xC618; 
    uint16_t blue  = 0x001F;

    gfx->fillRect(x, y + fh/2, fw, fh/2, blue);
    gfx->fillCircle(x + fw/2, y + fh/2, fw/4, blue);
    gfx->fillRect(x, y + fh/4, fw, fh/2, white);
    gfx->fillCircle(x + fw/2, y + fh/2, fw/4 - 1, grey);
    gfx->fillRect(x, y + fh/2, fw, fh/4, blue);
    gfx->fillRect(x, y, fw, fh/4, green);
    gfx->fillRect(x + fw/3, y, fw/3, fh/8, green);
  }
}

void drawStaticUI() {
  gfx->fillScreen(COL_BG);
  // Pi connection indicator dot
  gfx->fillCircle(SCREEN_W - 14, 14, 4, piConnected ? COL_GOOD : COL_BAD);

  // Draw title underline last so nothing overwrites it
  gfx->drawFastHLine(0, TITLE_H, SCREEN_W, 0x4208); // (Or COL_BORDER)
}

void displayWarmup(int secondsLeft) {
  gfx->fillRect(MAIN_X, TITLE_H, MAIN_W, SCREEN_H - TITLE_H, COL_BG);
  gfx->drawFastHLine(0, TITLE_H, SCREEN_W, 0x4208);
  gfx->setTextColor(COL_UNIT);
  gfx->setTextSize(2);
  int tw = 13 * 12;
  gfx->setCursor(MAIN_X + (MAIN_W - tw) / 2, 50);
  gfx->print("Warming up...");
  gfx->setTextSize(5);
  gfx->setTextColor(COL_TITLE);
  String s = String(secondsLeft) + "s";
  tw = s.length() * 30;
  gfx->setCursor(MAIN_X + (MAIN_W - tw) / 2, 85);
  gfx->print(s);
}

void drawStatsPanel(int x, int y, int rightX) {
  // LEFT SIDE: Min/max 12h
  gfx->setTextSize(1);
  gfx->setTextColor(COL_MUTED);
  gfx->setCursor(x, y);
  gfx->print("12H MIN / MAX");

  int valY = y + 16; // 16px gap below the header

  if (co2Max12h > co2Min12h) {
    gfx->setTextSize(2);
    gfx->setTextColor(COL_CO2);
    char minmaxBuf[24];
    // Formatted cleanly like "400 - 1200"
    snprintf(minmaxBuf, sizeof(minmaxBuf), "%d - %d", co2Min12h, co2Max12h);
    gfx->setCursor(x, valY);
    gfx->print(minmaxBuf);

    // Print "ppm" after the values
    gfx->setTextSize(1);
    gfx->setTextColor(COL_MUTED);
    int tw = strlen(minmaxBuf) * 12; // Size 2 text is approx 12px wide per char
    gfx->setCursor(x + tw + 6, valY + 6);
    gfx->print("ppm");
  } else {
    gfx->setTextSize(2);
    gfx->setTextColor(COL_MUTED);
    gfx->setCursor(x, valY);
    gfx->print("--");
  }

  // RIGHT SIDE: Uptime / Timestamp
  gfx->setTextSize(1);
  gfx->setTextColor(COL_MUTED);
  gfx->setCursor(rightX, y);
  gfx->print("SYSTEM TIME");

  unsigned long uptimeSecs = (millis() - startTime) / 1000;
  int uH = uptimeSecs / 3600;
  int uM = (uptimeSecs % 3600) / 60;
  int uS = uptimeSecs % 60;

  if (browserTimeOffset > 0) {
    // We have network time sync - show real time prominently
    unsigned long unix = browserTimeOffset + uptimeSecs + localTimeOffset;
    int s  = unix % 60; unix /= 60;
    int m  = unix % 60; unix /= 60;
    int h  = unix % 24;

    char timeBuf[16];
    snprintf(timeBuf, sizeof(timeBuf), "%02d:%02d:%02d", h, m, s);
    
    gfx->setTextSize(2);
    gfx->setTextColor(COL_WHITE); 
    gfx->setCursor(rightX, valY);
    gfx->print(timeBuf);

    // Print uptime in smaller text right below it
    char uptimeBuf[24];
    snprintf(uptimeBuf, sizeof(uptimeBuf), "up %dh %02dm", uH, uM);
    
    gfx->setTextSize(1);
    gfx->setTextColor(COL_MUTED);
    gfx->setCursor(rightX, valY + 18);
    gfx->print(uptimeBuf);
  } else {
    // No network sync yet — show uptime prominently instead
    char uptimeBuf[24];
    snprintf(uptimeBuf, sizeof(uptimeBuf), "%dh %02dm %02ds", uH, uM, uS);
    
    gfx->setTextSize(2);
    gfx->setTextColor(COL_WHITE);
    gfx->setCursor(rightX, valY);
    gfx->print(uptimeBuf);

    gfx->setTextSize(1);
    gfx->setTextColor(COL_MUTED);
    gfx->setCursor(rightX, valY + 18);
    gfx->print("uptime");
  }
}


#define GAP_SMALL 4

void displayReading(int co2) {
  if (!timeSynced) return;
  if (graphMode != 0) return;

  // Clear main area
  gfx->fillRect(0, TITLE_H, SCREEN_W, SCREEN_H - TITLE_H, COL_BG);

  int startX = 24; 
  int gap = 8;     
  int rightMargin = 24; 
  int trendIconW = 12;  

  // ==========================================
  //  PRE-CALCULATE LAYOUT 
  // ==========================================
  
  String numStr = String(co2);
  int co2NumW = numStr.length() * 30; // Size 5 roughly 30px per char
  int ppmW = 3 * 12;                  // Size 2 roughly 12px per char
  int co2EndX = startX + co2NumW + gap + ppmW + gap + 4 + trendIconW;
  int maxEndX = co2EndX;
  int sparkX = maxEndX + 16; 
  int sparkW = SCREEN_W - rightMargin - sparkX;
  if (sparkW < 20) sparkW = 20; 
  int sparkH = 28;

  // --- FIXED POSITION FOR SYSTEM INFO ---
  int sysInfoX = 186; // Used for top-right info AND bottom-right stats

  // ==========================================
  //  DRAWING
  // ==========================================

  int contentTop = TITLE_H;

  // --- NEW PRECISION LAYOUT MATH ---
  int labelToValGap = 20;
  int co2ValH = 40;
  int statsBlockH = 40;  // Dedicated height block for the statistics
  int blockSpacing = 30; // Gap between CO2 block and Stats block

  int totalH = labelToValGap + co2ValH + blockSpacing + statsBlockH;
  // Center vertically on screen
  int startY = TITLE_H + ((SCREEN_H - TITLE_H - totalH) / 2); 

  int co2Top    = startY;
  int valY      = co2Top + labelToValGap;
  int co2Bottom = valY + co2ValH;
  int midY      = co2Bottom + (blockSpacing / 2);
  int statsTop  = co2Bottom + blockSpacing;

  // --- SYSTEM INFO (Top Right) ---
  gfx->setTextSize(1);
  gfx->setTextColor(COL_TITLE);
  gfx->setCursor(sysInfoX, contentTop + 8); 
  gfx->print(deviceName);
  
  gfx->setTextColor(COL_MUTED);
  gfx->setCursor(sysInfoX, contentTop + 20);
  gfx->print("192.168.4.1");
  
  drawFlag(SCREEN_W - rightMargin - 18, contentTop + 8);

  // --- CO2 SECTION ---
  gfx->setTextSize(1.5);
  gfx->setTextColor(COL_MUTED); 
  gfx->setCursor(startX, co2Top);
  gfx->print("CARBON DIOXIDE");

  gfx->setTextSize(5); 
  gfx->setTextColor(COL_CO2);
  gfx->setCursor(startX, valY);
  gfx->print(numStr);

  gfx->setTextSize(2); 
  gfx->setTextColor(COL_MUTED);
  int unitX = startX + co2NumW + gap;
  int unitY = valY + (40 - 16); 
  gfx->setCursor(unitX, unitY);
  gfx->print("ppm");

  int trendX = unitX + ppmW + gap + 4;
  int trendY = unitY + 4;

  const char* trend = "-";
  if (prevCO2 >= 0) {
    if (co2 > prevCO2 + 5) trend = "^";
    else if (co2 < prevCO2 - 5) trend = "v";
  }
  drawTrendIcon(trendX, trendY, 5, trend, COL_CO2);

  int co2SparkY = valY + 40 - sparkH; 
  drawCO2Sparkline(sparkX, co2SparkY, sparkW, sparkH);

  // Floating horizontal divider line (Now correctly centered over stats)
  gfx->drawFastHLine(startX, midY, SCREEN_W - (startX * 2), COL_BORDER);

  // --- STATS SECTION --- 
  // We now pass sysInfoX to align the Time/Uptime stats cleanly on the right
  drawStatsPanel(startX, statsTop, sysInfoX);

  prevCO2 = co2;
}
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
void loop() {
  server.handleClient();
  // --- THE GATEKEEPER ---
  if (!timeSynced) {
    drawSyncWarning();
  }

  // Serial UI test commands
  if (Serial.available()) {
    String cmd = Serial.readStringUntil('\n');
    cmd.trim();
    if      (cmd == "ui")            drawStaticUI();
    else if (cmd == "warm")          displayWarmup(15);
    else if (cmd.startsWith("co2:")) displayReading(cmd.substring(4).toInt());
    else if (cmd.startsWith("status:"))  displayStatus(cmd.substring(7).c_str(), COL_GOOD);
    else if (cmd.startsWith("statusw:")) displayStatus(cmd.substring(8).c_str(), COL_WARN);
    else if (cmd.startsWith("statusb:")) displayStatus(cmd.substring(8).c_str(), COL_BAD);
  }

  // Touch
  bsp_touch_read();
  touch_data_t touch_data;
  if (bsp_touch_get_coordinates(&touch_data) && !calibrating) {
    unsigned long now = millis();

    // Only process touch if the debounce time has passed to prevent double-skips
    if (now - lastTouchTime > TOUCH_DEBOUNCE_MS) {
      lastTouchTime = now;

      if (graphMode != 0) {
        // We are on a graph. Cycle to the next view.
        graphMode = (graphMode + 1) % 2;  // 1->0->1...
        if (graphMode == 0) {
          drawStaticUI();
          displayReading(lastCO2);
        } else {
          if (timeSynced) {
            drawGraphView();
          } else {
            graphMode = 0;
            drawStaticUI();
            displayReading(lastCO2);
          }
        }
      } else {
        // We are on the main reading view.
        if (timeSynced) {
          graphMode = 1;
          drawGraphView();
        } else {
          drawSyncWarning();
        }
      }
    }
  }

  // K30 read
  if (!calibrating && millis() - lastReadTime >= READ_INTERVAL) {
    lastReadTime = millis();
    int co2 = readK30();
    unsigned long uptimeSecs = (millis() - startTime) / 1000;
    if (co2 != -1) {
      lastCO2 = co2;
      consecutiveFailures = 0;
      storeReading(co2, uptimeSecs);
      pushReadingToPi(co2);
      Serial.print("CO2: "); Serial.print(co2); Serial.println(" ppm");

      if (graphMode == 1) {
        drawGraphView();
      } else {
        displayReading(co2);
      }
    } else {
      consecutiveFailures++;
      Serial.println("CO2 read failed");
      if (consecutiveFailures >= 3) {
        displayStatus("CO2 disconnected", COL_WARN);
      }
    }
    // NEW: Calculate exactly how long those reads took
    readDuration = millis() - lastReadTime; 
  }

  // Progress bar — always animates in reading view
  drawProgressBar();

  // Refresh Pi indicator dot
  static unsigned long lastDotDraw = 0;
  static bool lastPiState = false;
  if (graphMode == 0 && (millis() - lastDotDraw >= 1000 || lastPiState != piConnected)) {
    lastDotDraw = millis();
    lastPiState = piConnected;
    gfx->fillCircle(SCREEN_W - 14, 14, 4, piConnected ? COL_GOOD : COL_BAD);
  }

  // Refresh stats panel every second (time display)
  static unsigned long lastStatsDraw = 0;
  
  // ADDED: && browserTimeOffset > 0
  if (graphMode == 0 && timeSynced && millis() - lastStatsDraw >= 1000) {
    lastStatsDraw = millis();
    
    int labelToValGap = 20;
    int co2ValH = 40;
    int statsBlockH = 40;
    int blockSpacing = 30;

    int totalH = labelToValGap + co2ValH + blockSpacing + statsBlockH;
    int startY = TITLE_H + ((SCREEN_H - TITLE_H - totalH) / 2); 

    int co2Top    = startY;
    int valY      = co2Top + labelToValGap;
    int co2Bottom = valY + co2ValH;
    int statsTop  = co2Bottom + blockSpacing;

    int startX   = 24;
    int sysInfoX = 186;

    gfx->fillRect(0, statsTop, SCREEN_W, (SCREEN_H - BAR_H) - statsTop, COL_BG);
    drawStatsPanel(startX, statsTop, sysInfoX);
  }

  delay(10);
}

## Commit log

2026-05-10 big commit
    [bom_co2_o2.csv, bom_co2_only.csv, bom_pi.csv]
2026-05-12 change button colour
